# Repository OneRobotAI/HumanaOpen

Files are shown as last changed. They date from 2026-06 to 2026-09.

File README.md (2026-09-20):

# HumanaOpen

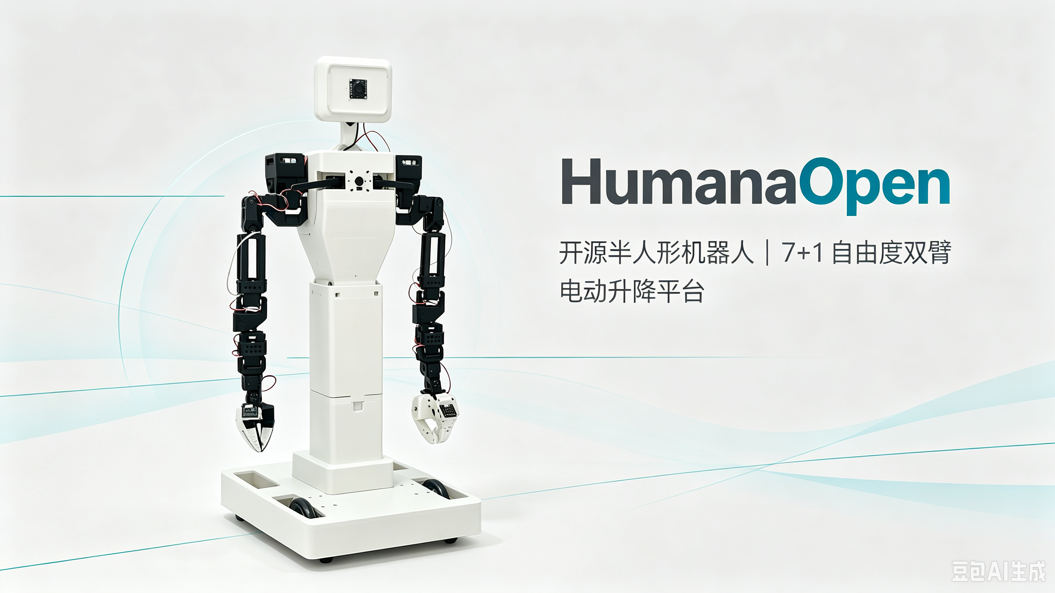
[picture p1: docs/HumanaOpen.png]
HumanaOpen


[English](README.md) | [中文](README_zh.md) | [Français](README_fr.md) | [한국어](README_ko.md)

**Open-source semi-humanoid robot — 7-DOF dual arms, differential drive, and leadscrew lift.**

Built on [LeRobot](https://github.com/huggingface/lerobot) and
[open-arms-mini](https://github.com/TheRobotStudio/open-arms-mini).

## Hardware

| Subsystem | Motors | Model |
|---|---|---|
| Left follower arm | 8 (7-DOF + gripper) | ST3215 C018 (1:345) |
| Right follower arm | 8 (7-DOF + gripper) | ST3215 C018 (1:345) |
| Head (pan/tilt) | 2 | ST3215 C018 (1:345) |
| Lift (leadscrew) | 1 | ST3250 (direct drive, no belt) |
| Differential drive base | 2 | ST3215 C018 (1:345) |
| Leader arms (teleop) | 2 × 8 | STS3215 C046 (1:147) |

> **Left/right convention**: Defined from the robot's own frame of reference.
> Standing behind the robot and facing the same direction as it, the arm on your
> left-hand side is the **left arm** (`port1`), the arm on your right-hand side is
> the **right arm** (`port2`). Wiring decides which physical arm is which; the
> software simply maps `left_arm_*` → `port1` and `right_arm_*` → `port2`.

## Software

```
lerobot_robot_humanaopen/
├── __init__.py              # Package exports
├── config_humanaopen.py     # HumanaOpenConfig, host/client configs
├── humanaopen.py            # HumanaOpen Robot class (follower)
├── lift_axis.py             # Lift axis with stall-detection homing
├── leader.py                # Leader teleoperator (single/bimanual)
├── humanaopen_host.py       # ZMQ host (robot-side, for dual-machine mode)
└── humanaopen_client.py     # ZMQ client (teleop-side)
examples/
├── record_data.py              # Data collection (single + dual-machine)
├── eval_data.py                # Inference (single + dual-machine)
├── teleop_leader_to_follower.py  # Full-body teleop: leader arms + keyboard
├── single_machine.py           # Single machine operation
├── teleop_keyboard.py          # Keyboard teleoperation via ZMQ
├── calibrate_follower.py       # Full follower-side calibration (arms+head+wheels+lift)
├── calibrate_leader.py         # Leader arm calibration (open-arms-mini)
├── diagnose_teleop.py          # Teleop joint direction diagnosis
├── test_base_keyboard.py       # Base-only keyboard test (no lift/arms)
├── test_lift_only.py           # Lift axis test (homing + raise/lower)
└── check_phase.py              # Check servo velocity unit (Phase BIT2)
```

## Hardware

```
hardware/
├── README.md               # Hardware overview (directory guide)
├── BOM/bom.md              # Bill of Materials — parts, specs, sourcing
├── assembly/assembly.md    # Step-by-step build instructions
├── cad/
│   ├── fusion360/          # Fusion 360 source designs (.f3d)
│   └── step/               # STEP exports (.step/.stp)
├── stl/                    # Ready-to-print 3D printing files (.stl)
├── urdf/                   # Robot description for RViz / Gazebo / simulation
│   └── humanaopen.urdf     # (meshes/ holds the referenced STL meshes)
└── electronics/wiring.md   # Wiring / electronics layout and power notes
```

### Diagnostics & Tuning Tools

| Script | Purpose |
|---|---|
| `diag_head_tilt_limits.py` | Head tilt mechanical range probe (before/after unlock) |
| `diag_head_tilt_range.py` | Head tilt range diagnostic |
| `diag_regression.py` | Regression test (lift + camera + teleop sequence) |
| `diag_st3250_speed.py` | ST3250 motor speed profiling (Phase BIT2=1) |
| `diag_follower_gripper.py` | Gripper joint diagnosis |
| `recover_lift_ping.py` | Lift motor communication ping |
| `speed_test_bit2_0.py` | BIT2=0 speed verification |
| `switch_phase_bit2.py` | Toggle ST3250 Phase BIT2 register |
```

## Quick Start

```bash
# 1. Create a conda env
conda create -n humanaopen python=3.12
conda activate humanaopen

# 2. Install LeRobot with all required extras (feetech + dataset + training + viz + hardware + smolvla)
pip install "lerobot[dataset,training,feetech,viz,transformers-dep,hardware,smolvla]"

# 3. Install HumanaOpen (editable)
cd /path/to/HumanaOpen
pip install -e . --no-deps

# Required: SOCKS proxy + SmolVLA tokenizer
pip install httpx[socks] num2words

# Optional: GPU with CUDA 12.8+ (Blackwell / RTX 5060+)
pip install torch torchvision torchaudio --index-url https://download.pytorch.org/whl/cu128

# 4. Verify installation
python -c "from lerobot_robot_humanaopen import HumanaOpen, HumanaOpenConfig; print('✅ OK')"

# 5. Verify installation (no calibration — just check import + connection)
python -c "
from lerobot_robot_humanaopen import HumanaOpen, HumanaOpenConfig
config = HumanaOpenConfig(port1='/dev/ttyACM0', port2='/dev/ttyACM1', port3=None, cameras={})
robot = HumanaOpen(config)
robot.connect(calibrate=False)
print(robot.get_observation().keys())
"

# 6. Dual-machine ZMQ mode (⚠️ for Jetson/Raspberry Pi deployment only — skip if single machine)
# See "Dual-Machine Deployment" section below for full setup guide.
```

## Dual-Machine Deployment

For production deployment, the robot hardware (servos + cameras) connects to an
embedded board (Jetson or Raspberry Pi), while the policy inference runs on a
separate GPU machine. The two communicate over ZMQ.

```
┌──────────────────────┐       ZMQ TCP        ┌──────────────────────┐
│   Dev Machine (GPU)  │ ←──────────────────→ │  Jetson / RPi (Host) │
│                      │   obs ──────────→    │                      │
│  • Policy inference  │   ←── action (21DOF) │  • Read servos/cams  │
│  • ACT / SmolVLA     │                       │  • Execute actions   │
│  • No servo wiring   │                       │  • Servo + cam wiring│
└──────────────────────┘                       └──────────────────────┘
```

### Raspberry Pi (Host only — no GPU inference)

```bash
# On Raspberry Pi (ARM64)
conda create -n humanaopen python=3.12
conda activate humanaopen

# Host dependencies (lightweight — no torch/transformers needed)
pip install pyzmq feetech-servo-sdk
# Optional: ffmpeg for video encoding (not needed if only streaming via ZMQ)
# conda install -y ffmpeg=7.1.1 -c conda-forge

# Install HumanaOpen
cd ~/ && git clone https://github.com/OneRobotAI/HumanaOpen.git
cd HumanaOpen && pip3 install -e . --no-deps

# Start Host — recommended: launcher script (bus topology + cameras via flags; same as teleop/record/eval scripts)
#   2-bus, no cameras                  python3 examples/humanaopen_host_launcher.py --no-cameras
#   2-bus, with cameras (default)      python3 examples/humanaopen_host_launcher.py
#   3-bus, with cameras                python3 examples/humanaopen_host_launcher.py --robot.port3 /dev/ttyACM2
#   3-bus, no cameras                  python3 examples/humanaopen_host_launcher.py --robot.port3 /dev/ttyACM2 --no-cameras
#   Override a camera device           python3 examples/humanaopen_host_launcher.py --head-camera /dev/video1
#   (--robot.port3 None = 2-bus; any device name = 3-bus. Defaults: head=/dev/video0, left_wrist=/dev/video2, right_wrist=/dev/video4)
#
# Equivalent inline form (also works):
python3 -c "
from lerobot_robot_humanaopen.humanaopen_host import HumanaOpenHost
from lerobot_robot_humanaopen import HumanaOpenConfig
from lerobot.cameras.opencv.configuration_opencv import OpenCVCameraConfig

HumanaOpenHost(HumanaOpenConfig(
    port1='/dev/ttyACM0', port2='/dev/ttyACM1', port3=None,
    cameras={
        'head':         OpenCVCameraConfig(index_or_path='/dev/video0', fps=30, width=640, height=480, fourcc='MJPG'),  # adjust /dev/videoN to match your board (lerobot-find-cameras)
        'left_wrist':   OpenCVCameraConfig(index_or_path='/dev/video2', fps=30, width=640, height=480, fourcc='MJPG'),  # adjust /dev/videoN to match your board (lerobot-find-cameras)
        'right_wrist':  OpenCVCameraConfig(index_or_path='/dev/video4', fps=30, width=640, height=480, fourcc='MJPG'),
                # 'chest': OpenCVCameraConfig(index_or_path='/dev/video6', fps=30, width=640, height=480, fourcc='MJPG'),  # 4th camera — uncomment to enable
    },
    wheel_dir_signs={'base_left_wheel': -1, 'base_right_wheel': 1}
)).run()
"
```

### NVIDIA Jetson (Host + optional local inference)

```bash
# On Jetson (JetPack 6.x, CUDA 12.x)
# Same installation as Raspberry Pi — Host does not need torch/transformers
conda create -n humanaopen python=3.12
conda activate humanaopen

pip install pyzmq feetech-servo-sdk
# conda install -y ffmpeg=7.1.1 -c conda-forge  # optional

cd ~/ && git clone https://github.com/OneRobotAI/HumanaOpen.git
cd HumanaOpen && pip3 install -e . --no-deps

# Start Host — recommended: launcher script (bus topology + cameras via flags; same as teleop/record/eval scripts)
#   2-bus, no cameras                  python3 examples/humanaopen_host_launcher.py --no-cameras
#   2-bus, with cameras (default)      python3 examples/humanaopen_host_launcher.py
#   3-bus, with cameras                python3 examples/humanaopen_host_launcher.py --robot.port3 /dev/ttyACM2
#   3-bus, no cameras                  python3 examples/humanaopen_host_launcher.py --robot.port3 /dev/ttyACM2 --no-cameras
#   Override a camera device           python3 examples/humanaopen_host_launcher.py --head-camera /dev/video1
#   (--robot.port3 None = 2-bus; any device name = 3-bus. Defaults: head=/dev/video0, left_wrist=/dev/video2, right_wrist=/dev/video4)
#
# Equivalent inline form (also works):
python3 -c "
from lerobot_robot_humanaopen.humanaopen_host import HumanaOpenHost
from lerobot_robot_humanaopen import HumanaOpenConfig
from lerobot.cameras.opencv.configuration_opencv import OpenCVCameraConfig

HumanaOpenHost(HumanaOpenConfig(
    port1='/dev/ttyACM0', port2='/dev/ttyACM1', port3=None,
    cameras={
        'head':         OpenCVCameraConfig(index_or_path='/dev/video0', fps=30, width=640, height=480, fourcc='MJPG'),  # adjust /dev/videoN to match your board (lerobot-find-cameras)
        'left_wrist':   OpenCVCameraConfig(index_or_path='/dev/video2', fps=30, width=640, height=480, fourcc='MJPG'),  # adjust /dev/videoN to match your board (lerobot-find-cameras)
        'right_wrist':  OpenCVCameraConfig(index_or_path='/dev/video4', fps=30, width=640, height=480, fourcc='MJPG'),
                # 'chest': OpenCVCameraConfig(index_or_path='/dev/video6', fps=30, width=640, height=480, fourcc='MJPG'),  # 4th camera — uncomment to enable
    },
    wheel_dir_signs={'base_left_wheel': -1, 'base_right_wheel': 1}
)).run()
"
```

> **Note**: Jetson can also run ACT inference locally (~100ms/frame on Orin),
> but SmolVLA requires a discrete GPU and should run on the dev machine.

### Dual-machine mode (--remote_ip)

All scripts (record, eval, teleop) support dual-machine mode via `--remote_ip`.
Single-machine mode (default) uses direct serial; dual-machine adds ZMQ:

```bash
# Single-machine (default — no --remote_ip needed)
python3 examples/record_data.py ...

# Dual-machine (add --remote_ip to any script)
python3 examples/record_data.py --remote_ip=192.168.1.100 --robot.cameras='{"head": {...}, "left_wrist": {...}, "right_wrist": {...}}'

python3 examples/eval_data.py --remote_ip=192.168.1.100 ...

python3 examples/teleop_leader_to_follower.py --remote_ip=192.168.1.100 ...
```

> **Note (recording)**: for `record_data.py` in dual mode, the `--remote_ip` script also
> passes the client-side camera list as a **schema** to define the dataset features.
> The Host must be started with the *same* cameras so it actually streams the images
> (start it with the camera configs, not `cameras={}`) — otherwise the recorded
> episodes contain state/action but no video.
>
> **Note (eval)**: the feature order of `observation.state` follows `robot.observation_features`
> (identical to training); `enable-base=true` keeps the `x.vel`/`theta.vel` columns.

### Network requirements

- Both machines on the same LAN (Ethernet recommended over WiFi for latency)
- Ports **5555** (commands) and **5556** (observations) must be open
- Image streaming bandwidth: ~10 Mbps per camera at 640x480 MJPG

### Performance

- **Control loop**: 60Hz (joint state read + action command)
- **Image capture**: 30fps (running in a dedicated background thread — does not block control)
- **Low latency**: image capture is decoupled from the control loop, so teleop arms respond
  instantly even at full 30fps image streaming
- **Configurable**: `image_fps_divider` (control/image rate ratio) and `max_loop_freq_hz` (control rate) in
  `HumanaOpenHostConfig`

### Wheel direction (dual-machine)

The robot's left wheel is mounted mirrored, so Host startup uses
`wheel_dir_signs={'base_left_wheel': -1, 'base_right_wheel': 1}`. This is set as the
default in `HumanaOpenConfig` — no need to pass it explicitly.

## Calibration

Calibration records the min/max range of each joint. **Only needed once** — the
results are saved and restored automatically on every connect.

### When to calibrate

- **First time setup** (required)
- After disassembling/reassembling arms or servos
- After replacing a servo motor
- After unlocking new motion range (e.g. head tilt EPROM unlock)

### Leader arm calibration

```bash
python3 examples/calibrate_leader.py
```

Steps (per arm):
1. Arm hanging straight down + gripper closed → `ENTER` (set zero point)
2. Move each joint through full range → `ENTER` (record real limits)
3. Gripper: close fully → `ENTER`, open fully → `ENTER`
4. Calibration saved automatically

> Requires leader arms powered at **7.4V** on `/dev/ttyACM2` (left) and `/dev/ttyACM3` (right).

Saved to:
```
~/.cache/huggingface/lerobot/calibration/teleoperators/humanaopen_leader/
├── leader_left.json
└── leader_right.json
```

### Follower calibration (arms + head + wheels + lift)

```bash
python3 examples/calibrate_follower.py
```

Steps:
1. Left arm + head: zero pose → `ENTER`; move joints through full range → `ENTER`
2. Right arm: zero pose → `ENTER`; move joints through full range → `ENTER`
3. Auto: wheels full range + lift stall homing to bottom

> Requires follower at **12V**. Torque is released during calibration — arms move freely.

Saved to:
```
~/.cache/huggingface/lerobot/calibration/robots/humanaopen/follower.json
```

## Teleoperation

### Full-body teleop (leader arms + keyboard)

`teleop_leader_to_follower.py` drives the follower's arms from the leader arms, and
head/base/lift from the keyboard:

| Control | Keys |
|---|---|
| Arms | leader arms follow (flips disabled — verified same-direction) |
| Head | `w`/`s` nod (up/down), `a`/`d` shake (left/right) |
| Base | `i`/`k` forward/back, `j`/`l` turn, `n`/`m` speed (0.3x/0.6x/1.0x) |
| Lift | `u`/`h` up/down (clamped 3–200mm) |
| Quit | `b` or Ctrl+C |

```bash
# Default: 3 cameras (head + left_wrist + right_wrist)
python3 examples/teleop_leader_to_follower.py

# Add the 4th chest camera
python3 examples/teleop_leader_to_follower.py --chest-camera /dev/video6

# Dual-machine: run Host on the robot, teleop on your PC
python3 examples/teleop_leader_to_follower.py --remote_ip=192.168.1.100 --chest-camera /dev/video6

# Teleop only, no cameras
python3 examples/teleop_leader_to_follower.py --no-cameras
```

##### Bus topology: 2-bus / 3-bus switch (`--robot.port3`)

The follower's serial buses are selected on the command line, so you can move
between layouts without editing code:

| Flag | Layout | Servos on each bus |
|---|---|---|
| *(omit)* / `--robot.port3 None` | **2-bus** (default) | bus1 = left arm + head, bus2 = right arm + **lift + wheels** |
| `--robot.port3 /dev/ttyACM2` | **3-bus** | bus1 = left arm + head, bus2 = right arm (exclusive), bus3 = lift + wheels |

The 3-bus layout takes the right arm off the bus shared with the lift/wheels,
giving it an uncontended bus (cleaner 60 Hz frame timing, less move-start
latency — most noticeable on the right arm). Both layouts run the same command;
`None` (or an empty value) selects 2-bus, a device name selects 3-bus:

```bash
# 2-bus (default): lift + wheels share port2 with the right arm
python3 examples/teleop_leader_to_follower.py

# Same thing, explicit
python3 examples/teleop_leader_to_follower.py --robot.port3 None

# 3-bus: give the lift + wheels their own serial port
python3 examples/teleop_leader_to_follower.py --robot.port3 /dev/ttyACM2

# Override other ports if your device names differ
python3 examples/teleop_leader_to_follower.py --robot.port1 /dev/ttyACM3 --robot.port2 /dev/ttyACM4
```

> The head servos (IDs 12, 13) stay on bus1 in both layouts — they are
> high-frequency (written every frame) like the left arm, while the lift/wheels
> are low-frequency (read every 10th frame), so bus3's job is to isolate the
> low-frequency group. Wiring note: the new port needs the same **GND
> common-ground** with the servo power supply.

#### Live display modes

`teleop_leader_to_follower.py` supports two visualization backends. Images are
decoded once by the control loop, then handed to a background display thread
so the 60 Hz control loop is never blocked.

| Flag | Backend | Notes |
|---|---|---|
| `--display=rerun` | [Rerun](https://rerun.io) native viewer | Native Rerun viewer window. |
| `--display=foxglove` | [Foxglove Studio](https://foxglove.dev) WebSocket | Connects Foxglove desktop or foxglove.dev to `ws://127.0.0.1:8765`. A layout is written to `examples/humanoopen_foxglove.layout.json` (import once). **Recommended** — lowest render latency of the two. |

Omit `--display` to run headless (no viewer).

```bash
# Foxglove (recommended)
python3 examples/teleop_leader_to_follower.py --remote_ip=192.168.1.100 --display=foxglove

# Rerun
python3 examples/teleop_leader_to_follower.py --remote_ip=192.168.1.100 --display=rerun
```

> **Display latency**: Both backends add a fixed render pipeline delay
> (≈1–1.5 s desktop / ≈2 s native viewer on this hardware) which is
> inherent to the visualization libraries. The action channel (arm
> commands) is real-time regardless; display lag does **not** affect
> recorded data quality — observation and action frames are always
> sampled synchronously.

Camera arguments: `--cameras=head,left_wrist` (subset), `--head-camera /dev/videoN`,
`--left-wrist-camera`, `--right-wrist-camera`, `--chest-camera` (each overrides the
device path; passing a `--*-camera` arg auto-adds that camera).

### Camera devices & fps (tested)

| Camera | Device | Format | FPS |
|---|---|---|-----|
| head | /dev/video0 | MJPG | 30 |
| left_wrist | /dev/video2 | MJPG | 30 |
| right_wrist | /dev/video4 | MJPG | 30 |
| chest | /dev/video6 | MJPG | 30 |

> **Adjusting FPS**: Check your camera's actual capabilities with
> `v4l2-ctl -d /dev/videoN --list-formats-ext`, then update the `fps` value in scripts.
> Setting an unsupported fps will cause a connection error at startup.

### Lift axis — zero persistence (免归零)

The lift is a 12-bit single-turn encoder (4096 ticks/rev) driving a leadscrew
(25 revs = 200mm). Absolute position is tracked in software via multi-turn wrap
tracking. Because the leadscrew is self-locking, the mechanical position survives
power cycles — so the zero position is persisted to `~/.cache/humanaopen/lift_zero.json`
and restored on the next connect, **skipping re-homing**:

- First connect: homes to the bottom (stall detection), saves the zero.
- Later connects: restores the saved absolute position (no movement needed).
- If the position changed (e.g. the lift was moved manually), restore fails and
  auto-homing runs instead.

Lift tuning (tested): `v_max=110` (raw), `kp_vel=10`, `home_down_speed=10` with
Phase BIT2=0 (50 step/s per raw unit). Max speed ≈ 8.7mm/s (200mm in ~23s).

### Lift speed boost (BIT2=0)

The ST3250 firmware maps `Goal_Velocity` with Phase BIT2=1 at 1 step/s per raw unit,
where raw > 1000 wraps direction (triangular wave) — unsafe. Switching Phase BIT2=0
changes the unit to 50 step/s per raw, so full speed (5500 step/s) is just raw 110,
entirely inside the reliable range. **After switching, all velocity params must be
divided by 50** (`home_down_speed`, `kp_vel`, `v_max`). Tools:
`examples/switch_phase_bit2.py` (toggle), `examples/speed_test_bit2_0.py` (verify).

> **Modern code does this automatically**: `lift_axis.configure()` reads the Phase
> register on every startup and, if BIT2=1 is detected, rewrites it to BIT2=0 (EPROM
> write — persists across reboots). `Acceleration` is also forced to 254 (fastest
> ramp) so commanded speeds are actually reached. No manual switching needed.

**After replacing the lift servo (safest manual fallback)**: a new servo ships with
Phase BIT2=1 (factory default), and the old `~/.cache/humanaopen/lift_zero.json`
holds the previous motor's encoder data — both need handling.

```bash
# 1. Remove the stale zero file (new motor has a different encoder origin)
rm ~/.cache/humanaopen/lift_zero.json

# 2. Check / switch the velocity unit (new servo ships BIT2=1 → set BIT2=0)
python3 examples/check_phase.py          # report current BIT2
python3 examples/switch_phase_bit2.py    # switch BIT2 → 0

# 3. First boot with forced homing to write the new motor's true zero
python3 -c "
from lerobot_robot_humanaopen.humanaopen_host import HumanaOpenHost
from lerobot_robot_humanaopen import HumanaOpenConfig
HumanaOpenHost(HumanaOpenConfig(
    port1='/dev/ttyACM0', port2='/dev/ttyACM1', port3=None,
    cameras={}, force_lift_home=True
)).run()
"
```

> Normal startup already performs steps 2–3 automatically; running them manually is
> a belt-and-braces check after a motor swap before going back to the full flow.

### Head tilt range unlock

The head tilt servo had its EPROM position limits baked to [1430, 2096] (~58°),
which the calibration file copied — limiting tilt to -54°/+4°. Writing
`Min=0 / Max=4095` unlocks the mechanical range [1367, 2242] (-61.6°/+17.1°):
`examples/unlock_head_tilt.py --probe`. After unlocking, the calibration file
(`~/.cache/huggingface/lerobot/calibration/robots/humanaopen/follower.json`) was
updated to the real range.

## Data Collection

The `lerobot-record` CLI hardcodes official robot types and rejects `humanaopen`
as an unrecognized choice. Use the Python API wrapper `examples/record_data.py`
instead — it exposes the **same parameter names** as `lerobot-record` and prints
the equivalent CLI command on startup for reference.

### 3 cameras (default)

```bash
python3 examples/record_data.py \
    --robot.type=humanaopen \
    --robot.id=follower \
    --robot.port1=/dev/ttyACM0 \
    --robot.port2=/dev/ttyACM1 \
    --robot.port3=None \
    --robot.cameras='{"head": {"type": "opencv", "index_or_path": "/dev/video0", "width": 640, "height": 480, "fps": 30, "fourcc": "MJPG"}, "left_wrist": {"type": "opencv", "index_or_path": "/dev/video2", "width": 640, "height": 480, "fps": 30, "fourcc": "MJPG"}, "right_wrist": {"type": "opencv", "index_or_path": "/dev/video4", "width": 640, "height": 480, "fps": 30, "fourcc": "MJPG"}}' \
    --robot.confirm_lift_after_home=true \
    --teleop.type=humanaopen_teleop \
    --teleop.left_arm_port=/dev/ttyACM2 \
    --teleop.right_arm_port=/dev/ttyACM3 \
    --teleop.flip_joints='{"left": [], "right": []}' \
    --teleop.joint_remap='{}' \
    --dataset.repo_id=your-name/humanaopen_demo \
    --dataset.single_task="describe your task" \
    --dataset.num_episodes=2 \
    --dataset.episode_time_s=15 \
    --dataset.reset_time_s=10 \
    --dataset.fps=30 \
    --dataset.push_to_hub=true
```

### 4 cameras (with chest for navigation)

Same as above, but replace the `--robot.cameras` JSON to include chest:

```bash
    --robot.cameras='{"head": {"type": "opencv", "index_or_path": "/dev/video0", "width": 640, "height": 480, "fps": 30, "fourcc": "MJPG"}, "left_wrist": {"type": "opencv", "index_or_path": "/dev/video2", "width": 640, "height": 480, "fps": 30, "fourcc": "MJPG"}, "right_wrist": {"type": "opencv", "index_or_path": "/dev/video4", "width": 640, "height": 480, "fps": 30, "fourcc": "MJPG"}, "chest": {"type": "opencv", "index_or_path": "/dev/video6", "width": 640, "height": 480, "fps": 30, "fourcc": "MJPG"}}' \
```

> **Note**: camera names must be consistent across record / train / rollout.

### Dual-machine (ZMQ): Host on the robot, record on your PC

When the follower runs on the robot (with its own cameras) and the leader arms
are plugged into your PC, record over ZMQ. **Start the Host first**, then run
`record_data.py` on the PC:

```bash
# 1) On the robot (Jetson or Raspberry Pi, see "Installing: Raspberry Pi / Jetson"
#    above) — start the Host, then leave it running
#    (HumanaOpenHost(...).run() with port1/port2 + the 3 cameras).

# 2) On your PC — record (follower via ZMQ, leader via local serial ttyACM0/1)
python3 examples/record_data.py \
    --remote_ip=192.168.1.9 \
    --robot.cameras='{"head": {"type": "opencv", "index_or_path": "/dev/video0", "width": 640, "height": 480, "fps": 30, "fourcc": "MJPG"}, "left_wrist": {"type": "opencv", "index_or_path": "/dev/video2", "width": 640, "height": 480, "fps": 30, "fourcc": "MJPG"}, "right_wrist": {"type": "opencv", "index_or_path": "/dev/video4", "width": 640, "height": 480, "fps": 30, "fourcc": "MJPG"}}' \
    --teleop.left_arm_port=/dev/ttyACM0 \
    --teleop.right_arm_port=/dev/ttyACM1 \
    --teleop.flip_joints='{"left": [], "right": []}' \
    --teleop.joint_remap='{}' \
    --dataset.repo_id=your-name/humanaopen_demo \
    --dataset.single_task="describe your task" \
    --dataset.num_episodes=2 \
    --dataset.episode_time_s=15 \
    --dataset.reset_time_s=10 \
    --dataset.fps=30 \
    --dataset.push_to_hub=true \
    --display=foxglove
```

- `--remote_ip` switches to dual-machine mode: the follower connects to the Host
  over ZMQ (follower `port1/port2`, `--robot.type/id/port3` are **not** needed),
  while the leader arms use the PC's local serial ports.
- `--robot.cameras` is passed as a *schema* (names + resolutions); the Host owns
  the physical cameras and streams the images over ZMQ.
- `--display=foxglove` (optional) streams cameras + state to the Foxglove app on
  the PC (connect Studio to `ws://127.0.0.1:8765`); `--display=rerun` uses the
  native Rerun viewer. Omit `--display` to record headless.

### Controls during recording

| Control | Keys |
|---|---|
| Arms | leader arms follow (16 DOF) |
| Head | `w`/`s` nod, `a`/`d` shake (2 DOF) |
| Base | `i`/`k` forward/back, `j`/`l` turn (2 DOF, speed `n`/`m`) |
| Lift | `u`/`h` up/down with safety limits (1 DOF, clamped 3–200mm) |
| Record | `C` start, `Q` quit, `A` re-record episode |
| Confirm | After homing, hold `u`/`h` to position, `ENTER` to confirm |

The `--teleop.type=humanaopen_teleop` teleoperator records **all 21 DOF** — the
leader arms (16 joints) plus keyboard-controlled head/lift/base (5 DOF). Both are
saved into the dataset for ACT training.

### Lift behavior during recording

- On first connect: lift **homes to bottom** (stall detection), saves the zero
  position to `~/.cache/humanaopen/lift_zero.json`.
- On subsequent connects: lift **restores the saved position** (no homing needed),
  unless the position changed (manual push → restore fails → auto-home).
- After homing: keyboard hold `u`/`h` adjusts height with safety limits
  (3mm–200mm), `ENTER` to confirm and start recording.

### Resuming / cleaning datasets

If a dataset directory already exists from a previous run, delete it or resume:

```bash
rm -rf ~/.cache/huggingface/lerobot/your-name/humanaopen_demo    # fresh start
# or add --dataset.resume=true to the record_data.py command     # continue from last episode
```

### Live display while recording (optional)

By default recording runs headless (no viewer). To watch cameras + state in real
time while you teleoperate, add a display flag:

```bash
# Rerun viewer
python3 examples/record_data.py ... --display=rerun

# Foxglove app (recommended — lower render latency, same backend as teleop)
python3 examples/record_data.py ... --display=foxglove
# connect Foxglove Studio to ws://127.0.0.1:8765
```

> Display is decoupled from the control/recording loop, so it never perturbs the
> recorded `(observation, action)` frames. Like teleop, the viewer adds a fixed
> ~1–1.5 s render delay that does **not** affect data quality.

## Training

### ACT (action chunking transformer)

```bash
# Quick test (2 episodes)
lerobot-train \
    --policy.type=act \
    --policy.device=cuda \
    --policy.push_to_hub=true \
    --policy.repo_id=your-name/humanaopen_act_policy \
    --dataset.repo_id=your-name/humanaopen_act_demo \
    --output_dir=outputs/humanaopen_act_demo \
    --batch_size=3 \
    --steps=5

# Production (>50 episodes)
lerobot-train \
    --policy.type=act \
    --policy.device=cuda \
    --policy.push_to_hub=true \
    --policy.repo_id=your-name/humanaopen_act_policy \
    --dataset.repo_id=your-name/humanaopen_act_demo \
    --output_dir=outputs/humanaopen_act_demo \
    --batch_size=32 \
    --steps=50000
```

### SmolVLA (vision-language-action model)

SmolVLA requires the language instruction from `--dataset.single_task` (used during recording).
The VLM weights (~500M) are downloaded automatically from HuggingFace on first run.

```bash
# Quick test (2 episodes)
lerobot-train \
    --policy.type=smolvla \
    --policy.device=cuda \
    --policy.push_to_hub=true \
    --policy.repo_id=your-name/humanaopen_smolvla_policy \
    --dataset.repo_id=your-name/humanaopen_act_demo \
    --output_dir=outputs/humanaopen_smolvla_demo \
    --batch_size=4 \
    --steps=20
```

> **Note**: SmolVLA (~450M params) is ~20x heavier than ACT (~52M), uses more VRAM,
> and trains slower. Batch size 4 fits in 8GB VRAM (RTX 5060 Ti). For >50 episodes,
> increase steps to 20000+.

### Key parameters

| Parameter | Default | Description |
|---|---|---|
| `--policy.type` | — | **Required.** `act`, `smolvla`, `diffusion`, etc. |
| `--policy.device` | `cuda` | `cuda` / `cpu`. |
| `--policy.push_to_hub` | `true` | Push model to HuggingFace Hub. |
| `--policy.repo_id` | — | Hub repo for the trained model. Required when pushing. |
| `--dataset.repo_id` | — | **Required.** Hub repo of the training dataset. |
| `--output_dir` | — | Local checkpoint directory. |
| `--batch_size` | 8 | Samples per step. ACT: 32, SmolVLA: 4 (8GB VRAM limit). |
| `--steps` | 100000 | Total training steps. ACT: 50K, SmolVLA: 20K. |

### Outputs

```
outputs/humanaopen_act_demo/
├── pretrained_model/           # Full model (config + weights)
├── last/pretrained_model       # Latest checkpoint
├── train_logs/                 # Training metrics (TensorBoard-compatible)
└── training_state.json         # Optimizer/scheduler state for resume
```

The pushed model will be at `https://huggingface.co/your-name/humanaopen_act_policy`.

## Inference (Deployment)

> **Dependencies**: SmolVLA requires `transformers>=4.48` and `num2words`.
> Install with `pip install transformers>=4.48 num2words` before running SmolVLA inference.

### ACT inference

**Dual-machine (recommended):** the robot runs a Host (Jetson/Raspberry Pi) with the
cameras; `eval_data.py` connects to it over ZMQ on your PC. Start the Host first, then:

```bash
# On the robot (Jetson or Raspberry Pi) — start the Host and leave it running
#   (HumanaOpenHost(...).run() with port1/port2 + the 3 cameras).

# On your PC — run inference
python3 examples/eval_data.py \
    --policy.type=act \
    --policy.repo_id=your-name/humanaopen_act_policy \
    --policy.device=cuda \
    --remote_ip=192.168.1.9 \
    --robot.cameras='{"head": {"type": "opencv", "index_or_path": "/dev/video0", "width": 640, "height": 480, "fps": 30, "fourcc": "MJPG"}, "left_wrist": {"type": "opencv", "index_or_path": "/dev/video2", "width": 640, "height": 480, "fps": 30, "fourcc": "MJPG"}, "right_wrist": {"type": "opencv", "index_or_path": "/dev/video4", "width": 640, "height": 480, "fps": 30, "fourcc": "MJPG"}}' \
    --enable-base=false \
    --enable-lift=false \
    --num-episodes=5 \
    --duration=30 \
    --fps=30 \
    --display=foxglove
```

- `--remote_ip` switches to dual-machine mode: the follower connects to the Host
  over ZMQ (no `--robot.port1/port2/port3`); the cameras live on the Host.
- `--display=foxglove` (optional) streams to the Foxglove app on the PC
  (connect Studio to `ws://127.0.0.1:8765`). Omit `--display` for headless inference.

**Single-machine** (follower directly on serial ports, same machine):
```bash
python3 examples/eval_data.py \
    --policy.type=act \
    --policy.repo_id=your-name/humanaopen_act_policy \
    --policy.device=cuda \
    --robot.type=humanaopen \
    --robot.id=follower \
    --robot.port1=/dev/ttyACM0 \
    --robot.port2=/dev/ttyACM1 \
    --robot.port3=None \
    --robot.cameras='{"head": {"type": "opencv", "index_or_path": "/dev/video0", "width": 640, "height": 480, "fps": 30, "fourcc": "MJPG"}, "left_wrist": {"type": "opencv", "index_or_path": "/dev/video2", "width": 640, "height": 480, "fps": 30, "fourcc": "MJPG"}, "right_wrist": {"type": "opencv", "index_or_path": "/dev/video4", "width": 640, "height": 480, "fps": 30, "fourcc": "MJPG"}}' \
    --enable-base=false \
    --enable-lift=false \
    --num-episodes=5 \
    --duration=30 \
    --fps=30
```

### SmolVLA inference (language-conditioned)

**Dual-machine (recommended):** same as ACT — start the Host on the robot, run on
your PC over ZMQ:

```bash
# On the robot — start the Host and leave it running.

# On your PC
python3 examples/eval_data.py \
    --policy.type=smolvla \
    --policy.repo_id=your-name/humanaopen_smolvla_policy \
    --policy.device=cuda \
    --task="wave hello with both arms" \
    --remote_ip=192.168.1.9 \
    --robot.cameras='{"head": {"type": "opencv", "index_or_path": "/dev/video0", "width": 640, "height": 480, "fps": 30, "fourcc": "MJPG"}, "left_wrist": {"type": "opencv", "index_or_path": "/dev/video2", "width": 640, "height": 480, "fps": 30, "fourcc": "MJPG"}, "right_wrist": {"type": "opencv", "index_or_path": "/dev/video4", "width": 640, "height": 480, "fps": 30, "fourcc": "MJPG"}}' \
    --enable-base=false \
    --enable-lift=false \
    --num-episodes=2 \
    --duration=10 \
    --fps=10 \
    --display=foxglove
```

**Single-machine** (follower directly on serial):
```bash
python3 examples/eval_data.py \
    --policy.type=smolvla \
    --policy.repo_id=your-name/humanaopen_smolvla_policy \
    --policy.device=cuda \
    --task="wave hello with both arms" \
    --robot.type=humanaopen \
    --robot.id=follower \
    --robot.port1=/dev/ttyACM0 \
    --robot.port2=/dev/ttyACM1 \
    --robot.port3=None \
    --robot.cameras='{"head": {"type": "opencv", "index_or_path": "/dev/video0", "width": 640, "height": 480, "fps": 30, "fourcc": "MJPG"}, "left_wrist": {"type": "opencv", "index_or_path": "/dev/video2", "width": 640, "height": 480, "fps": 30, "fourcc": "MJPG"}, "right_wrist": {"type": "opencv", "index_or_path": "/dev/video4", "width": 640, "height": 480, "fps": 30, "fourcc": "MJPG"}}' \
    --enable-base=false \
    --enable-lift=false \
    --num-episodes=2 \
    --duration=10 \
    --fps=10
```

> **SmolVLA performance note**: VLM inference is ~1s/frame (450M params). A 10s
> episode at 10fps = 100 frames ≈ 100s wall clock time. For real-time deployment,
> use ACT (~50ms/frame). SmolVLA is best for language-conditioned tasks.

### Live display during inference (optional)

Display is off by default. Add `--display` to stream the rollout live:

```bash
# Foxglove app (recommended — lower render latency)
python3 examples/eval_data.py ... --display=foxglove
# connect Foxglove Studio to ws://127.0.0.1:8765

# Rerun native viewer
python3 examples/eval_data.py ... --display=rerun

# Headless (default): omit --display
python3 examples/eval_data.py ...
```

> Display runs in a background thread so it never slows the policy loop. Like
> teleop/record, the ~1–1.5 s render delay is inherent to the viewer and does not
> affect control.

### Base control (disable by default)

By default the base wheels are **disabled** (`--enable-base=false`): the policy's
predicted `x.vel` / `theta.vel` are forced to `0`, so only the arms, head and lift
move. This prevents the robot from driving away unexpectedly, which is safer while
validating a new policy.

```bash
# Base disabled (default, safer) — wheels stay still, only arms/head/lift move
python3 examples/eval_data.py ... --enable-base=false

# Base enabled — policy is allowed to drive the wheels
python3 examples/eval_data.py ... --enable-base=true
```

Start with `--enable-base=false` until the policy behaves well, then enable the
base if your task requires locomotion.

### Lift control (hold height by default)

By default the lift is **held at its current height** (`--enable-lift=false`): the
policy's `lift_axis.height_mm` is overridden to the current height each frame, so
the lift does not move (the policy can otherwise output 0 and drag the lift to the
bottom).

```bash
# Lift held at current height (default, safer) — the lift stays put
python3 examples/eval_data.py ... --enable-lift=false

# Lift enabled — policy controls the lift height
python3 examples/eval_data.py ... --enable-lift=true
```

Start with the lift held, then enable it once your task requires changing height.

### Controls during inference

| Control | Keys |
|---|---|
| Quit | `q` or Ctrl+C |

### Safety: torque release on exit

When you press `q` / Ctrl+C to stop inference, the script will:
1. **Stop the base wheels** (send `x.vel=0 / theta.vel=0` as the final command) and
   hold the lift at its current height
2. Save the lift position
3. Prompt: **"Press ENTER to release torque and disconnect..."**
4. Hold the arms before pressing ENTER — torque will be released and arms drop freely
5. Press ENTER when ready → disconnect

This prevents arms from suddenly dropping when servos lose power.

**Base/lift auto-stop safety net (dual-machine):** the Host runs a watchdog — if it
receives no action command for `watchdog_timeout_ms` (500 ms), it zeroes the wheel
velocity and holds the lift. So even if the PC process is killed abruptly
(`kill -9`) or disconnects while the wheels are moving, the base stops on its own
instead of continuing to drive until the Host is stopped.

### Key parameters (inference)

| Parameter | Default | Description |
|---|---|---|
| `--policy.type` | `act` | `act` or `smolvla`. |
| `--policy.repo_id` | — | **Required.** Hub repo of the trained model. |
| `--task` | — | Language instruction (required for SmolVLA). |
| `--enable-base` | `false` | Set `true` to allow policy control of base wheels. Default: disabled. |
| `--enable-lift` | `false` | Set `true` to let the policy control the lift height. Default: held at current height. |
| `--num-episodes` | 5 | Number of inference episodes. |
| `--duration` | 30 | Seconds per episode. |
| `--fps` | 30 | Inference frequency (Hz). |

On startup, the script will prompt for calibration confirmation (ENTER to restore).
On exit, it will prompt for torque release confirmation (ENTER to release).

## Navigation

Language-driven navigation powered by [LightNav-0](https://github.com/kyonofx/LightNav-0) — a vision-language-action model running on your GPU PC. The robot only runs a light ZMQ adapter; no LightNav install, no ROS, no lidar, no map needed. Just a forward RGB camera plus the GPU server over the network.

```
[chest camera /dev/video0] ──cv2──> [adapter on Jetson] ──WS──> lightnav-serve (GPU PC, :8050)
        ^                                   |
        |                                   | 10×SE(2) waypoints / step
  HumanaOpenHost <──ZMQ :5555── [control law: official waypoint_command]
```

Quick start (on the robot, two terminals):

```bash
# Terminal 1 — Host in pure-base mode (no camera streaming; adapter reads the chest cam itself)
python3 -c "
from lerobot_robot_humanaopen.humanaopen_host import HumanaOpenHost
from lerobot_robot_humanaopen import HumanaOpenConfig

HumanaOpenHost(HumanaOpenConfig(
    port1='/dev/ttyACM0', port2='/dev/ttyACM1', port3=None,
    cameras={},
    wheel_dir_signs={'base_left_wheel': -1, 'base_right_wheel': 1}
)).run()
"

# Terminal 2 — navigation adapter (GPU PC must have lightnav-serve listening on 0.0.0.0:8050)
NO_PROXY="192.168.1.12" python3 examples/lightnav_navigation.py \
    --lightnav ws://192.168.1.12:8050 \
    --camera /dev/video0 \
    --instruction "walk forward slowly"
```

Key points:
- **English instructions only** (model is English-trained); e.g. `"walk forward slowly"`, `"go to the object on your left"`.
- `NO_PROXY=<gpu_ip>` is required on the robot: the `websockets` client reads proxy env vars and will fail to reach the LAN GPU server otherwise.
- RVQ quantization traps (waypoint yaw = ±0.314 rad for "no turn", 0.15 m steps) are handled inside the adapter via the official `waypoint_command` control law + deadbands — see `docs/navigation/lightnav_integration.md` §八/§九 for the full pitfall log.

## Roadmap

| Module | Status |
|---|---|
| ACT, SmolVLA | ✅ |
| BOM | ✅ |
| Assembly | ✅ |
| CAD | ✅ |
| Lite version | ☐ |
| URDF | ☐ |
| Agent | ☐ |
| Vision-based grasping | ☐ |
| Vision-based navigation | ✅ |
| Embodied world models | ☐ |

### Acknowledgements

- Software is built on [LeRobot](https://github.com/huggingface/lerobot) and
  [open-arms-mini](https://github.com/TheRobotStudio/open-arms-mini).
- The arms are based on open-arms-mini, with a [PincOpen](https://github.com/pollen-robotics/PincOpen?tab=readme-ov-file) gripper added at the end of each arm.
- Hardware design references [xlerobot](https://github.com/xrobot/xlerobot):
  the head degrees-of-freedom and the differential-drive base follow its
  approach.

## Contact & Cooperation

- **Product Communication**: scan the QR code to reach our product team:

Product communication QR code

## License

Apache 2.0

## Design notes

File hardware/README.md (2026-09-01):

# Hardware

The mechanical / electrical / printable design files for HumanaOpen.

## Directory layout

| Path | Contents |
|---|---|
| [`BOM/`](BOM/bom.md) | Bill of Materials — every part needed to build the robot, with specs, quantity, and sourcing. |
| [`assembly/`](assembly/assembly.md) | Step-by-step build instructions (subsystems: arms, head, lift, base, electronics). |
| [`cad/`](cad/) | CAD source files. |
| `cad/fusion360/` | Fusion 360 source design files (`.f3d`). |
| `cad/step/` | STEP file exports (`.step`/`.stp`, open, importable anywhere). |
| [`stl/`](stl/) | Ready-to-print 3D printing files (`.stl`). |
| [`urdf/`](urdf/) | Robot description (`.urdf` / `.xacro`) for RViz / Gazebo / simulation. |
| `urdf/meshes/` | Mesh files referenced by the URDF (may reuse the STL meshes). |
| [`electronics/`](electronics/wiring.md) | Wiring / electronics layout and power notes. |

## Conventions

- **Units**: STL/STEP are in millimetres (mm).
- **URDF**: inertial properties should be filled from the CAD export so
  simulation matches the physical robot.
- Keep every exported STEP/STL in sync with the Fusion 360 source: re-export
  after any design change and note the revision in the file name or this README.

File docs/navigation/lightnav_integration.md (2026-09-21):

# HumanaOpen 导航 — LightNav-0 集成调研与实施方案

> 状态：**调研完成，模拟验证通过，实机接入完成（直行 + 转向测试通过）**
> 日期：2026-09-17（调研）/ 2026-09-18（实机接入）
> 硬件：PC (RTX 5060 Ti 16GB) 为 GPU 推理服务器，Jetson 为机器人端

## 一、结论摘要

- **LightNav-0 可行**：已在 PC 上完成环境安装、模型加载、MuJoCo 模拟语言导航全链路验证（全 PASS）。
- **HumanaOpen 代码零修改**：导航作为"外挂"，通过约 50 行 ZMQ adapter 与 HumanaOpen 底盘接口衔接。
- **不需要 ROS 层**（最小方案）；ROS 2 完整栈是可选升级，非前提。
- **传感器需求极简**：只需一个前向 RGB 摄像头（无激光雷达、无深度、无地图、无里程计）。

## 二、LightNav-0 是什么

- **VLM 导航模型**（Qwen3-VL-4B 底座）：输入单目 RGB 历史帧 + 自然语言指令 → 输出 10 个 SE(2) 未来航点 `[forward_m, lateral_m, yaw_rad]`。
- **不是 SLAM / move_base / 地图框架**：无定位、无建图、无障碍感知层；纯端到端视觉语言 → 航点，每帧重规划。
- 单模型覆盖：语言指令导航（VLN）、开放词汇找物（ObjectNav）、视觉目标追踪（EVT），跨机器人零样本迁移（官方演示过 humanoid/quadruped/wheeled/aerial）。
- 项目主页/源码：`lightorigins/LightNav-0`，Apache 2.0，arXiv 2608.30935。
- 模型权重：HuggingFace `LightOriginsHQ/LightNav-0`（需 HF 登录；仓库内文件 ~9.6GB）。

## 三、硬件与运行要求

| 项 | 要求 | 实测（本机 5060 Ti） |
|---|---|---|
| GPU | ~15GB 显存（4B bf16 ~10GB + KV cache ~2.3GB）| ✅ 16GB 可用，占用 ~8.7GiB |
| 架构 | 官方验证 sm_103 (B300)；消费级 Blackwell (sm_120) 实测可跑 | ✅ |
| Python | >=3.11, <3.12 | ✅ 独立 conda 环境 `lightnav` |
| torch | >=2.9；**Blackwell 需 cu129 wheel**（2.10.0+cu129）| ✅ |
| vLLM | **0.19.1 精确锁定**（绑定私有 API）| ✅ |
| 推理延迟 | 官方 60-150ms/步；本机实测 644ms/步（warmup 后）| 可用 |

传感器：**单目 RGB 前向摄像头**（参考：Orbbec Gemini 330, 640×360@30；任意 rgb8 相机可）。
机器人：任意移动底盘；官方参考 Unitree Go2 / LimX TRON1；**MuJoCo demo 用差速 TurtleBot（与 HumanaOpen 同运动学）**。

## 四、部署架构（与 HumanaOpen 的关系）

```
┌─ LightNav 世界 ─────────────┐      ┌─ HumanaOpen 世界 ─────────────┐
│ GPU 服务器 (PC)              │      │ Jetson 机器人端                 │
│  lightnav-serve :8050        │      │  HumanaOpenHost (ZMQ 5555/5556) │
│  ←WebSocket JSON→            │      │  底盘吃 x.vel / theta.vel       │
│        │                     │      │                                │
│        └─ 航点 → ZMQ adapter ─┼────▶│  差速电机                      │
│    (adapter 约 50 行 Python) │      │                                │
└──────────────────────────────┘      └────────────────────────────────┘
```

- **模型服务器**：GPU 机器（PC），跑 `lightnav-serve`，是独立 conda 环境 `lightnav`。
- **客户端（adapter）**：Jetson 上，相机 → JPEG → WebSocket `next` → 拿航点 → 换算 `v=forward/dt, w=yaw/dt` → ZMQ 发给 HumanaOpenHost 的 `x.vel/theta.vel`。
- **HumanaOpen 代码不改**：adapter 只向已有的 ZMQ action 塞值。

### 可选：ROS 2 完整栈（暂不采用）
官方 `robot_deploy/` 是 ROS 2 Humble 栈（相机驱动 + vln_client + vln_mpc + vln_web + 适配器），提供 MPC 平滑、Web 控制面板、看门狗、手自动切换。**需要装 ROS 2 + 写 humano_adapter**，工作量大，暂缓。

## 五、安装步骤（已在 PC 完成，存档）

```bash
# 1. 独立 Python 3.11 环境
conda create -n lightnav python=3.11 -y
conda activate lightnav

# 2. Blackwell 必需：cu129 torch（普通 cu12.8 无法 JIT）
pip install torch==2.10.0+cu129 torchvision==0.25.0+cu129 \
  --index-url https://download.pytorch.org/whl/cu129

# 3. LightNav 本体
cd ~/LightNav-0
pip install -e ".[vllm,video]"

# 4. HF 登录（代理环境需先装 socksio）
pip install "httpx[socks]"
hf auth login --token <TOKEN> --add-to-git-credential

# 5. 下载权重
mkdir -p checkpoints/LightNav-0
hf download LightOriginsHQ/LightNav-0 --local-dir checkpoints/LightNav-0

# 6. GPU 冒烟测试（全 PASS 才继续）
MODEL_PATH=checkpoints/LightNav-0 bash scripts/smoke_gpu.sh
```

## 六、启动模型服务器（GPU 机器上常驻）

```bash
cd ~/LightNav-0 && conda activate lightnav
CUDA_VISIBLE_DEVICES=0 GPU_MEM_UTIL=0.78 \
HOST=0.0.0.0 PORT=8050 lightnav-serve \
    --task vln \
    --model_path checkpoints/LightNav-0 \
    --backend vllm_local
```

- 监听 `127.0.0.1:8050`（本机）。**要让 Jetson 连接必须监听对对外地址**，启动前确认 `lightnav-serve` 的 host 参数（或设 `--host 0.0.0.0`）。
- 首次启动含模型加载+JIT 编译约 1-2 分钟；之后单步推理约 100-644ms。
- 显存不够时把 `GPU_MEM_UTIL` 降到 0.70。

## 七、MuJoCo 模拟验证（已通过）

```bash
# 服务终端保持运行，另开终端：
cd ~/LightNav-0/mujoco_demo
./run.sh --vln-server ws://127.0.0.1:8050
# 浏览器打开 http://127.0.0.1:8088，输入英文指令（如 "walk to the red trash can"）
```

- 模拟差速 TurtleBot（与 HumanaOpen 同运动学）在 ProcTHOR 室内场景语言导航。
- 模型英文训练，**中文指令不支持**，请用英文。

## 八、接入 HumanaOpen（已实施）

### ZMQ adapter（实际实现：`examples/lightnav_navigation.py`）

在 Jetson 上运行（Jetson 只需 `pip install websockets`，无需安装 LightNav/GPU 推理——模型全部在 PC 上跑）：

```bash
cd ~/HumanaOpen && git pull
# 启动 HumanaOpenHost（纯底盘，相机由 adapter 自抓）
python3 -c "
from lerobot_robot_humanaopen.humanaopen_host import HumanaOpenHost
from lerobot_robot_humanaopen import HumanaOpenConfig

HumanaOpenHost(HumanaOpenConfig(
    port1='/dev/ttyACM0', port2='/dev/ttyACM1', port3=None,
    cameras={},   # 导航不需要 host 传图，adapter 自己抓 chest 相机
    wheel_dir_signs={'base_left_wheel': -1, 'base_right_wheel': 1}
)).run()
"
# 另一个终端：跑导航 adapter
NO_PROXY="192.168.1.12" python3 examples/lightnav_navigation.py \
    --lightnav ws://192.168.1.12:8050 \
    --zmq-host 127.0.0.1 \
    --camera /dev/video0 \
    --instruction "walk forward slowly"
```

工作流程：
1. `cv2` 抓 chest 相机一帧 → JPEG（q80，640x360）→ WebSocket 发给 PC 的 lightnav-serve
2. 服务返回 10 个 SE(2) 航点 `[forward_m, lateral_m, yaw_rad]`（RVQ 量化）
3. **控制律**（移植 LightNav 官方 mujoco demo 的 `waypoint_command`，非"航点÷dt"的朴素除法）：
   - 只用 `waypoints[0]`（当前帧的动作；后面的是预测路径，用了会放大 atan2 噪声导致满档旋转）
   - distance < 0.08m → 视为量化噪声，静止 `(0,0)`
   - `angular = clamp(1.8·bearing + 0.25·target_yaw)`，bearing/yaw 各带死区滤量化电平
   - `linear = clamp(0.75·distance·cos(bearing), 0, 0.35)`；`|bearing|>65°` 时 linear=0（先转向再前进）
4. `{"x.vel": v m/s, "theta.vel": w deg/s}` 经 ZMQ PUSH 发到 HumanaOpenHost:5555

关键点：
- `stop=true` 或航点空 → 发 `{x.vel:0, theta.vel:0}`；Ctrl+C 也会主动归零（而非只靠 watchdog）
- **RVQ 量化陷阱**（实机踩坑记录）：action tokenizer 把"无转向"量化成 `yaw=±0.314`（≈±π/10），把"直行一步"量化成 `forward≈0.15m`。直接 `yaw/dt` 会得到 ±72°/s 的疯狂自转；直接 `forward/dt` 是 0.6 m/s 的冲撞速度。必须用上述官方控制律 + 死区。
- **代理变量**：`websockets` 库会读 http/socks 代理环境变量，Jetson 上连局域网 GPU 必须 `NO_PROXY=192.168.1.12`，否则连不上。
- **语音/中文**需要额外 ASR/翻译层（模型英文训练）——不在当前方案范围。

### 相机
- 实机使用 Jetson 的 `Integrated_Webcam_HD`（USB，原生 MJPG 1280x720@30 / YUYV 640x480@25）作为 **chest 前向相机 `/dev/video0`**。
- 注意：这台相机 lerobot 的 `OpenCVCamera` 无法设置分辨率（`set()` 恒返回 False），因此 host 用 `cameras={}` 纯底盘模式，图像完全由 adapter 的 `cv2` 直接抓取（`cv2.VideoCapture` 读 `/dev/video0` 正常）。
- 模型内部把任意分辨率缩放到其 `video_size`，客户端只需 JPEG 编码。

## 九、实机验证结果（2026-09-18）

### 环境
- Jetson（host，`humanaopen` conda env，Python 3.12）：HumanaOpenHost 纯底盘模式 + adapter；唯一外设：chest 相机 `/dev/video0`
- PC（GPU，`lightnav` env）：lightnav-serve 常驻 `0.0.0.0:8050`，模型 8.7GiB 显存

### 关键数据
| 项 | 实测 |
|---|---|
| 单帧推理延迟（Jetson→PC→Jetson RTT） | **~200-350ms**（比 644ms 的纯本机 warmup 快，服务常驻后更稳）|
| 直行 `"walk forward slowly"` | **0.113 m/s 平稳直行**，无自转、无抖动 |
| 左转弧线 `"go to the object on your left"` | **0.11 m/s + 15°/s 左转**（模型输出 lateral=0.022m → bearing=8.4° → 1.8×=15°/s）|
| 静止（噪声航点）| **精确归零**——RVQ 量化噪声（yaw=±0.314）被死区滤掉，不再 ±72°/s 狂转 |
| Watchdog 联动 | host 500ms 超时正常；adapter 4Hz 控制周期在超时内 |

### 踩坑记录（按时间顺序）
1. **`host+cameras` 启动崩溃**：`OpenCVCamera(/dev/video0)` 校验失败——这台 USB 相机 `set(CAP_PROP_*)` 恒返 False，`lerobot` 把它当失败。→ 改用 `cameras={}` 纯底盘模式。
2. **±72°/s 自转**（首批测试）：直接 `yaw/dt`，量化 `±0.314rad` 变成满档旋转。→ 引入官方 `waypoint_command`。
3. **±45°/s 抖动**（第二批）：官方 0.35m 距离门槛在 0.15m 步长下全被当噪声，回退 `valid[-1]` 放大 atan2 符号噪声。→ 门槛降到 0.08m + bearing/yaw 死区。
4. **-45°/s 残留**（第三批）：搜索"第一个够远点"时，序列后面的远点 bearing 极大，overrode waypoint[0]。→ 只用 `waypoint[0]` 作为当前帧动作。

### 结论
- **导航链路完整可用**：相机 → GPU 推理 → 控制律 → 底盘，全部打通。
- 模型对"左右/前进"的语义理解正确，会输出对应的横向位移 + 转向组合。
- 当前速度保守（0.11 m/s、15°/s）；调参可改 `--max-linear` / `--max-angular`。

## 十、风险与注意

| 项 | 说明 |
|---|---|
| **无避障** | 模型只看 RGB，感知不到视野外的障碍；紧急停止靠 `stop` 标志 + 用户 WASD/手动控制 |
| **延迟** | 实测单步 ~200-350ms（约 3-5Hz 重规划）；远距离移动建议用平滑器，不能每步都突变 |
| **中文指令** | 模型英文训练；中文需要先做翻译/ASR |
| **服务对外** | lightnav-serve 必须监听 `0.0.0.0` 才能被 Jetson 连（`HOST=0.0.0.0` 环境变量） |
| **代理** | Jetson 连 `ws://192.168.1.12:8050` 需 `NO_PROXY=192.168.1.12`（websockets 读代理变量） |
| **显存** | 16GB 偏紧；跑服务时关闭其他 GPU 大程序 |
| **换伺服/换环境** | 不影响导航（导航只依赖相机+GPU） |

## 文件结构

```
docs/navigation/
└── lightnav_integration.md    # 本文档（HumanaOpen 侧）
HumanaOpen 侧实现:
examples/lightnav_navigation.py  # ZMQ adapter：相机抓帧 → ws → 控制律 → 底盘
External:
~/LightNav-0/                   # LightNav 仓库（独立项目，不并入 HumanaOpen）
  ├── src/lightnav/             # 模型推理 + WebSocket 服务
  ├── robot_deploy/             # （可选）ROS2 参考栈
  ├── mujoco_demo/              # 差速机器人仿真（已验证）
  └── docs/                     # PROTOCOL/DEPLOYMENT/CONFIGURATION
```

## 十一、后续路线

- [x] 环境安装 + GPU 冒烟测试（全 PASS）
- [x] 模型服务启动
- [x] MuJoCo 模拟语言导航验证
- [x] 确认 Jetson 前向相机（chest `/dev/video0`，`Integrated_Webcam_HD`）
- [x] 让服务监听 0.0.0.0
- [x] 编写 ZMQ adapter（Jetson 上，`examples/lightnav_navigation.py`）
- [x] HumanaOpen + LightNav 实机端到端测试（直行 + 左转弧线均通过）
- [ ] 避障增强（当前模型无避障，仅 RGB 语义导航）
- [ ] 调参优化速度/转向手感（`--max-linear` / `--max-angular`）
- [ ] 目标点停止精度验证（`stop` 标志在实机上的到位表现）

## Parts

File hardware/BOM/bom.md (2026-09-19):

# Bill of Materials (BOM)

Complete parts list to build one HumanaOpen. Quantities are per robot.

> Work in progress — sections are filled in as the build is completed.

## Cost summary

The control board is optional.

| Section | Subtotal (RMB) |
|---|---|
| Mechanical / structure | 290 |
| 3D printed parts | 300 |
| Motion / actuation | 4,110 |
| Electronics (excl. control board) | 953 |
| Cables / misc | 65 |
| **Total (excl. control board, excl. fasteners)** | **≈ 5,718** |

## Mechanical / structure

### Differential base

| Part / description | Spec / size | Qty | Unit price | Total | Source |
|---|---|-----|---|---|---|
| Caster wheel (differential-drive base) | 5 inch (12.7 cm) | 2 | 33 RMB | 66 RMB | [link](https://e.tb.cn/h.8KjMwtvPCctqYIB?tk=8CsCTTQGr5Y) |
| Swivel caster wheel | Ø25 mm, wheel width 13 mm, base 39 × 33 mm, mounting hole pitch 30 × 24 mm, mounting height 37.5 mm | 2 | 3 RMB | 6 RMB | [link](https://e.tb.cn/h.8KvHhYsMbquYeNy?tk=0FWcTTwToO5) |
| Ball bearing | 6706RS, 30 × 37 × 4 mm | 2 | 11 RMB | 22 RMB | [link](https://e.tb.cn/h.8ppes1EsjZbPZ7G?tk=j67IT6WceLJ) |

### Lift structure

| Part / description | Spec / size | Qty | Unit price | Total | Source |
|---|---|-----|---|---|---|
| Graphite self-lubricating bronze bushing | 8 × 15 × 24 mm | 2 | 6 RMB | 12 RMB | [link](https://e.tb.cn/h.8LyLe0PfJWP7vzO?tk=2RPvT6qeK39) |
| T-leadscrew with brass nut | T8 × 300 mm | 1 | 12 RMB | 12 RMB | [link](https://e.tb.cn/h.8MsdKG0YofaR0MA?tk=FcbUTTjETcR) |
| Bearing (bearing 608-2Z, iron shield) — Japan VBI | 8 × 22 × 7 mm | 1 | 1 RMB | 1 RMB | [link](https://e.tb.cn/h.8KWfffzVtRIZkMB?tk=IkvxT6Jfnwz) |
| Aluminium rigid coupling | Ø20 × 25 mm, bores Ø8 / Ø6 | 1 | 4 RMB | 4 RMB | [link](https://e.tb.cn/h.8K8vuIaWV6FE6xU?tk=vCWeTTQZ5ji) |
| Bus-servo flat-shaft flange (A servo horn) | A-style servo horn | 1 | 12 RMB | 12 RMB | [link](https://e.tb.cn/h.8LBtAQFkrs6S6lb?tk=qVBvTTQV6sU) |
| Hardened precision shaft | Ø8 × 310 mm, hardened | 2 | 3.5 RMB | 7 RMB | — |
| Aluminium extrusion (M6 tapped holes at both ends) | 2040 EU-spec silver, 300 mm | 1 | 10 RMB | 10 RMB | [link](https://e.tb.cn/h.8oH8sbI8ngX3S5c?tk=VQAlTTQObBL) |

### Leader arm

| Part / description | Spec / size | Qty | Unit price | Total | Source |
|---|---|-----|---|---|---|
| Aluminium extrusion | 3060 EU-spec silver | 1 | 30 RMB | 30 RMB | — |
| Aluminium plate | 200 × 300 mm, M6 holes — 116 mm hole spacing along the 200 mm side, 30 mm along the 300 mm side | 1 | 100 RMB | 100 RMB | — |
| Aluminium extrusion corner bracket | 3060, 90° double-slot | 2 | 4 RMB | 8 RMB | [link](https://qr.1688.com/s/aVNYKMW5) |

## 3D printed parts

Filament: **PLA / PETG** (Bambu Lab PLA Basic / Anycubic PLA, or PETG for
stronger structural parts). A large-build-volume printer (e.g. Anycubic Kobra
3 MAX) is required for the large printed parts.

| Part / description | STL file | Qty | Total cost | Notes |
|---|---|-----|---|---|
| PLA / PETG printed parts | [`stl/HumanaOpen_stl/`](../stl/HumanaOpen_stl/) (17 parts), [`stl/Open-arms-mini-stl/`](../stl/Open-arms-mini-stl/) (21 parts) | 6 | ≈ 300 RMB | Requires a large-format printer (Anycubic Kobra 3 MAX) |

## Fasteners

| Part / description | Spec | Qty |
|---|---|-----|
| Chassis servo bracket screws | M3*22 | 8 |
| Chassis caster wheel screws | M3*12 | 8 |
| Drive wheel hub screws | M3*12 | 8 |
| Drive wheel hub washers | M3 | 8 |
| Drive wheel screws | M3*25 | 10 |
| Chassis self-tapping screws | M3*20 (self-tapping) | 32 |
| Lift aluminium extrusion screws | M6*12 (hex socket) | 4 |
| Lift connector screws | M3*10 | 4 |
| Lift base mounting screws | M3*20 (self-tapping) | 4 |
| Lift inner printed part screws | M5*22 | 8–16 |
| Lift outer bearing screws | M4*16 (flat head) | 4 |
| Lift outer bearing nuts | M4 | 4 |
| Arm shoulder screws | M6*20 | 16 |
| Chest RGB camera screws | M2*12 | 4 |
| Body mounting screws | M3*10 (self-tapping) | 4 |
| Neck screws | M3*20 | 2 |
| Head RGB camera screws | M2*10 | 4 |
| Display screws | M3.5*8 | 4 |

## Motion / actuation

| Part / description | Model | Qty | Unit price | Total | Source |
|---|---|-----|---|---|---|
| Follower arm servos (left + right, 8 each) | FEETECH ST3215 C018 | 16 | 110 RMB | 1,760 RMB | [link](https://e.tb.cn/h.8KS047iJugyLfv9?tk=DSDWTTSxLeS) |
| Head servos (pan + tilt) | FEETECH ST3215 C018 | 2 | 110 RMB | 220 RMB | [link](https://e.tb.cn/h.8KS047iJugyLfv9?tk=DSDWTTSxLeS) |
| Lift motor | FEETECH ST3250 | 1 | 310 RMB | 310 RMB | [link](https://e.tb.cn/h.8LwGPtampPRo6fc?tk=uCJATT7aXjl) |
| Base wheel motors (left + right) | FEETECH ST3215 C018 | 2 | 110 RMB | 220 RMB | [link](https://e.tb.cn/h.8KS047iJugyLfv9?tk=DSDWTTSxLeS) |
| Leader arm servos (left + right, 8 each) | FEETECH ST3215 C046 | 16 | 100 RMB | 1,600 RMB | [link](https://e.tb.cn/h.8KS047iJugyLfv9?tk=DSDWTTSxLeS) |

## Electronics

| Part / description | Model / spec | Qty | Unit price | Total | Source |
|---|---|-----|---|---|---|
| Main control board (Host) — optional | Raspberry Pi 5 4GB | 1 | 1,200 RMB | 1,200 RMB | — |
| Main control board (Host) — optional | Jetson Orin Nano Super 8GB | 1 | 3,800 RMB | 3,800 RMB | — |
| Camera (head/left_wrist/right_wrist/chest) | 720P 90° distortion-free USB | 4 | 70 RMB | 280 RMB | [link](https://e.tb.cn/h.8KRXD6pf6IHHQNu?tk=Liq1TT8421C) |
| Follower (from) power supply | 12V 4A | 1 | 20 RMB | 20 RMB | — |
| Leader (master) power supply | 7.3V 3A | 2 | 20 RMB | 40 RMB | — |
| Bus servo driver board | Waveshare (微雪) bus servo driver | 2 | 27 RMB | 54 RMB | [link](https://e.tb.cn/h.8Lya2xQuOF0N34m?tk=HTlUTT8TJLG) |
| Battery | 20000mAh 140W dual Type-C + USB-A | 1 | 399 RMB | 399 RMB | — |
| Display (optional) | 7" touch with case, 1024×600 | 1 | 160 RMB | 160 RMB | [link](https://e.tb.cn/h.8JQRkOZKPsCPwZ7?tk=60rcT7YLj2W) |

## Cables / misc

| Part / description | Spec | Qty | Unit price | Total | Source |
|---|---|-----|---|---|---|
| USB-to-Type-C cable | USB 3.2, 10 Gbps | 2 | 8.5 RMB | 17 RMB | [link](https://e.tb.cn/h.8KRq9s1kJBHLtdN?tk=yS9XTT8GzSZ) |
| Y-split Type-C to DC 5521 cable | 0.5 m | 1 | 20 RMB | 20 RMB | [link](https://e.tb.cn/h.8KRHy0GP3Zk8Rw8?tk=UkoSTT8Dq9k) |
| USB to DC 5521 cable (optional, Raspberry Pi) | 0.5 m | 1 | 7 RMB | 7 RMB | [link](https://e.tb.cn/h.8J9K33ZS7bNSVQz?tk=PukJT71DTRR) |
| Type-C to DC 5521 cable (optional, Jetson) | 0.5 m | 1 | 9 RMB | 9 RMB | [link](https://e.tb.cn/h.8qUeZkgpcKBiZ6R?tk=239sT7cfg4G) |
| Terminal wire | 3P 5264 reverse terminal wire, 1000 mm | 1 | 3 RMB | 3 RMB | [link](https://e.tb.cn/h.8oTllunUw9ECpZp?tk=PRvNT60hcKX) |
| Terminal wire | 3P 5264 reverse terminal wire, 500 mm | 1 | 3 RMB | 3 RMB | [link](https://e.tb.cn/h.8oTllunUw9ECpZp?tk=PRvNT60hcKX) |
| Terminal wire | 3P 5264 reverse terminal wire, 200 mm | 2 | 3 RMB | 6 RMB | [link](https://e.tb.cn/h.8oTllunUw9ECpZp?tk=PRvNT60hcKX) |
| Chest camera cable (optional) | 100 mm | 1 | included with camera | — | — |
| Head camera cable | 300 mm | 1 | included with camera | — | — |
| Wrist camera cable | 900 mm | 2 | included with camera | — | — |

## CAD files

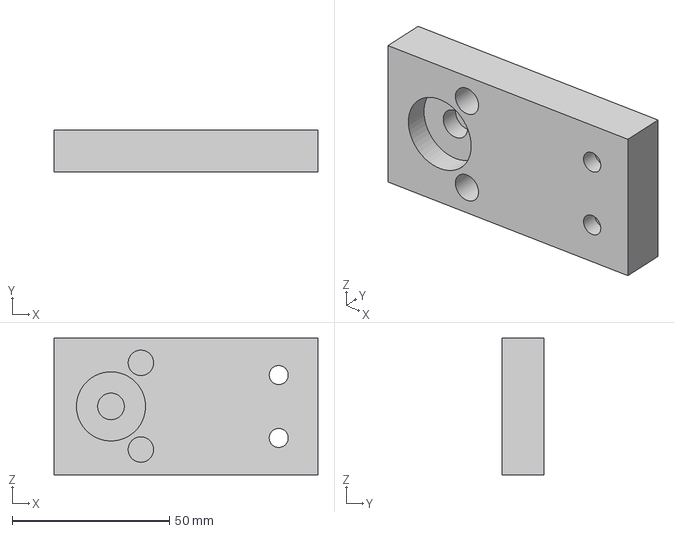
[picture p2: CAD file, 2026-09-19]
hardware/cad/step/HumanaOpen_step/8.LiftTopMount-V1.step
84.0 x 13.5 x 43.5 mm

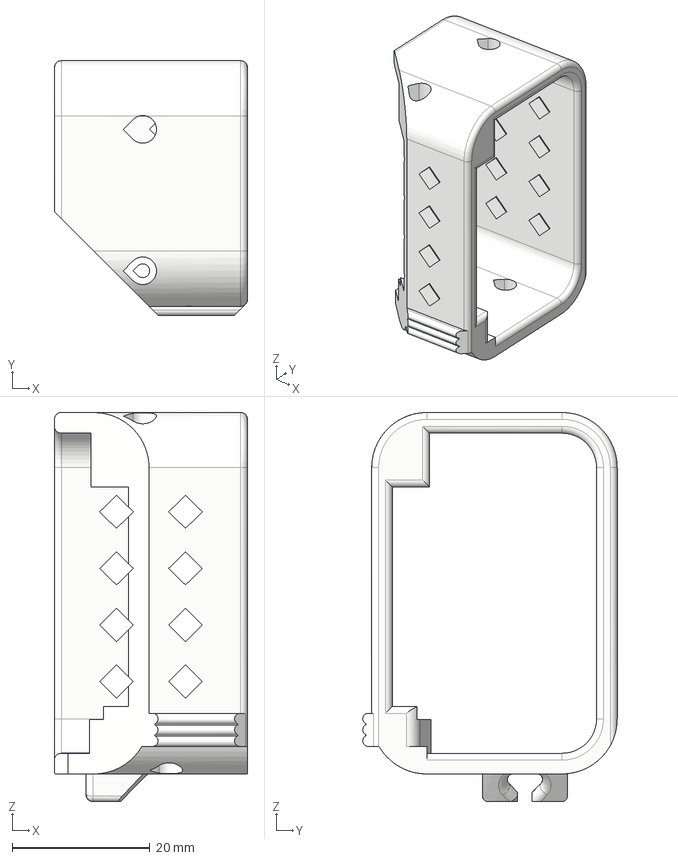
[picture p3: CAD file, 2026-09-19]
hardware/cad/step/Open-arms-mini_step/J4_holder.step
28.0 x 36.9 x 56.4 mm
Wiring_holder v1
Wiring_holder v1 (1)

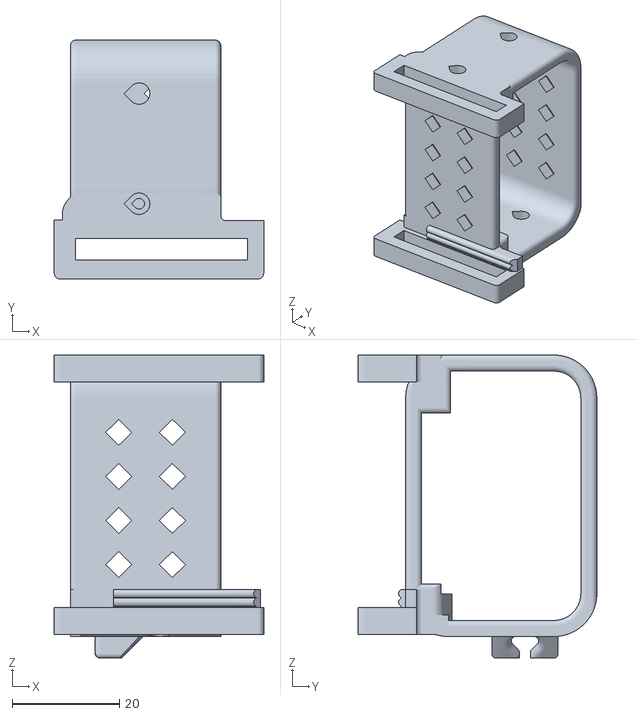
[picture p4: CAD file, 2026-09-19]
hardware/stl/Open-arms-mini-stl/J6 holder with strap v4.stl
39.0 x 44.4 x 56.4

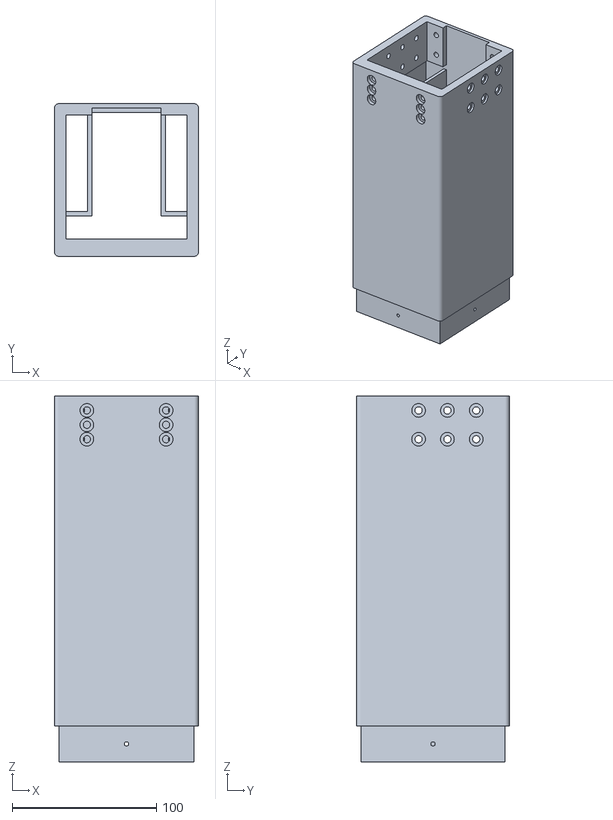
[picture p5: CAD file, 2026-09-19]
hardware/urdf/meshes/9.LiftSlider-V12.stl
100.0 x 106.0 x 254.0

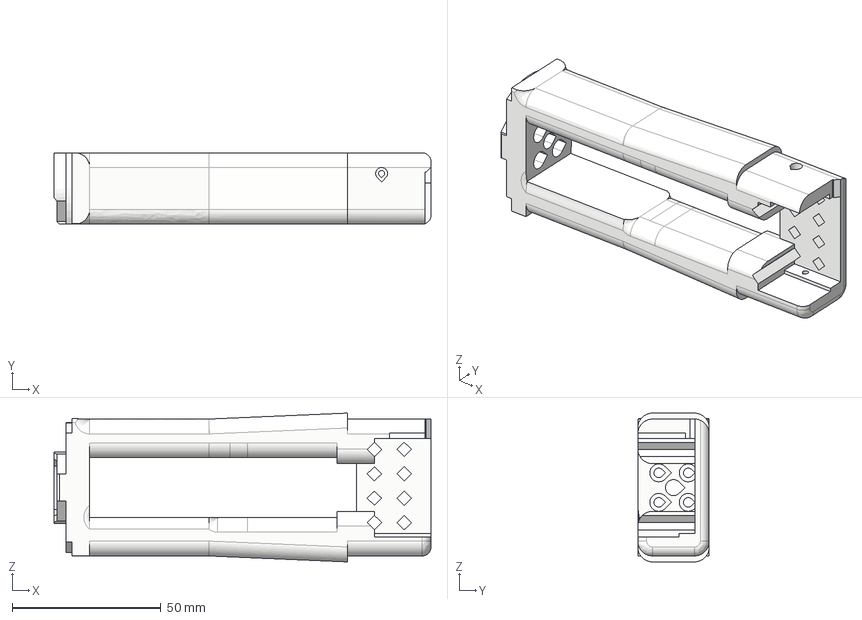
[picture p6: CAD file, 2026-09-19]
hardware/cad/step/Open-arms-mini_step/J4.step
126.6 x 24.0 x 50.0 mm
Wiring_holder v1
Wiring_holder v1 (1)
Wiring_holder v1 (2)
Wiring_holder v1 (1) (1)
Wiring_holder v1 (3)

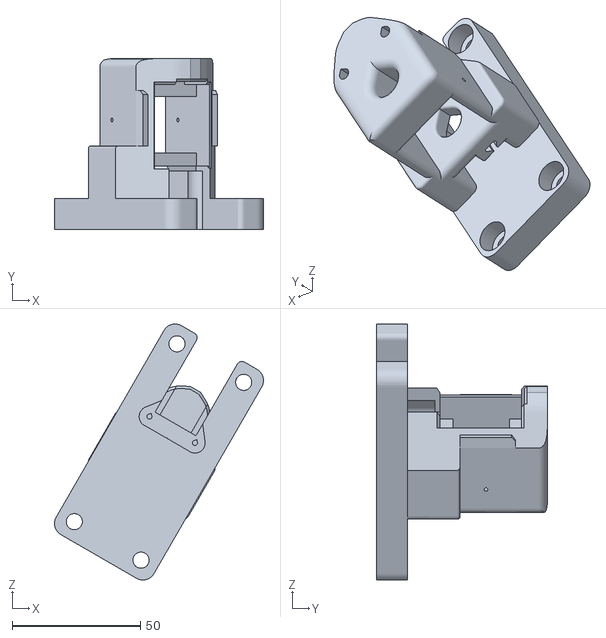
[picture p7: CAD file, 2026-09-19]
hardware/urdf/meshes/J1 v5.stl
81.4 x 66.5 x 99.7

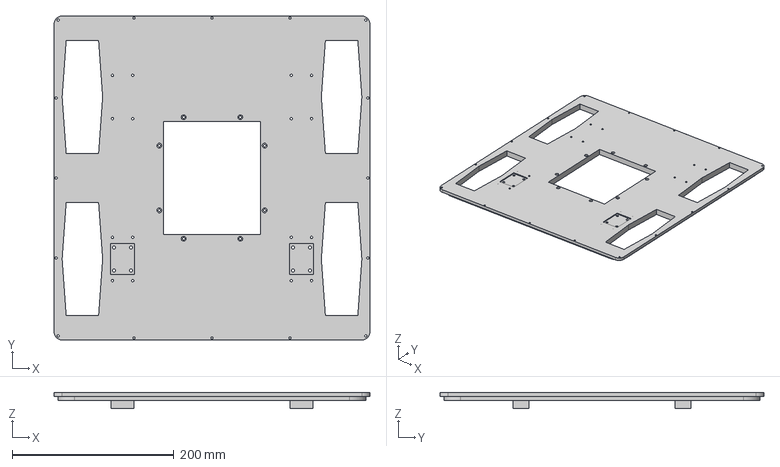
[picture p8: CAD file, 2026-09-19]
hardware/cad/step/HumanaOpen_step/5.LowerBase-V15.step
390.0 x 400.0 x 20.0 mm

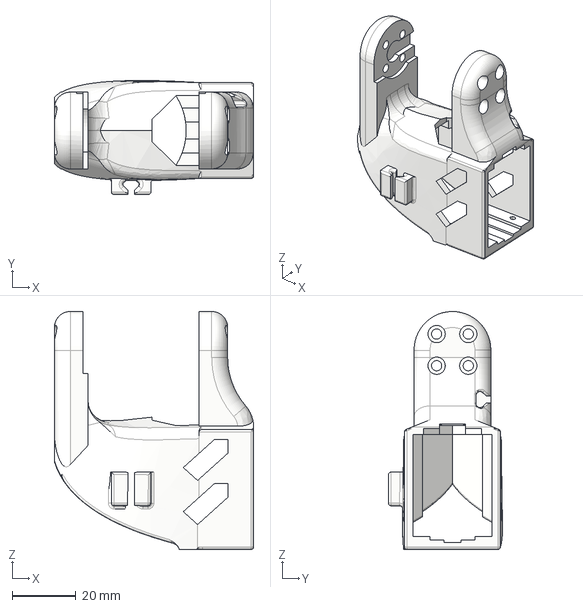
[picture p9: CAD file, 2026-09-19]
hardware/cad/step/Open-arms-mini_step/J5.step
62.3 x 35.6 x 74.4 mm

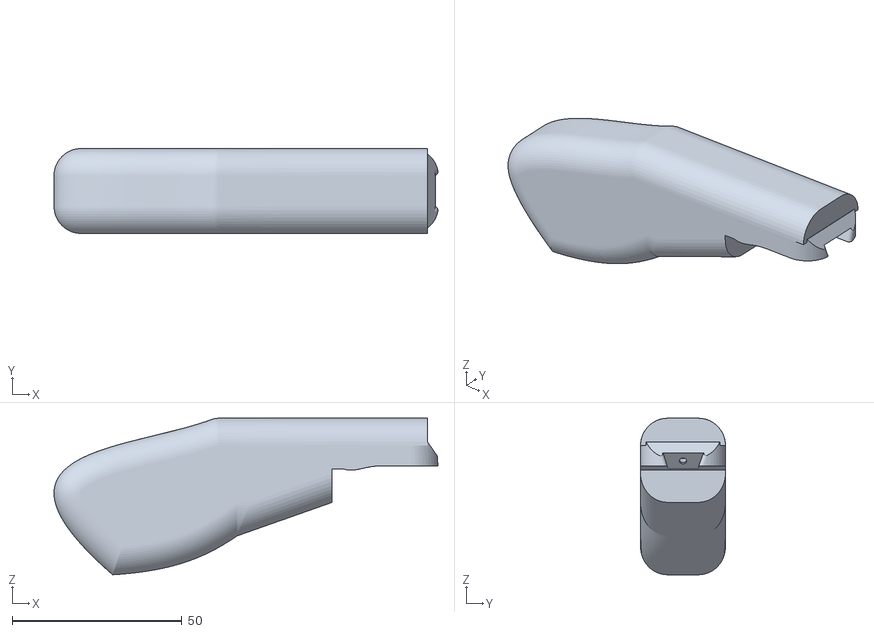
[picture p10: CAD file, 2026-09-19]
hardware/stl/Open-arms-mini-stl/J Handle v12.stl
113.0 x 25.0 x 46.1

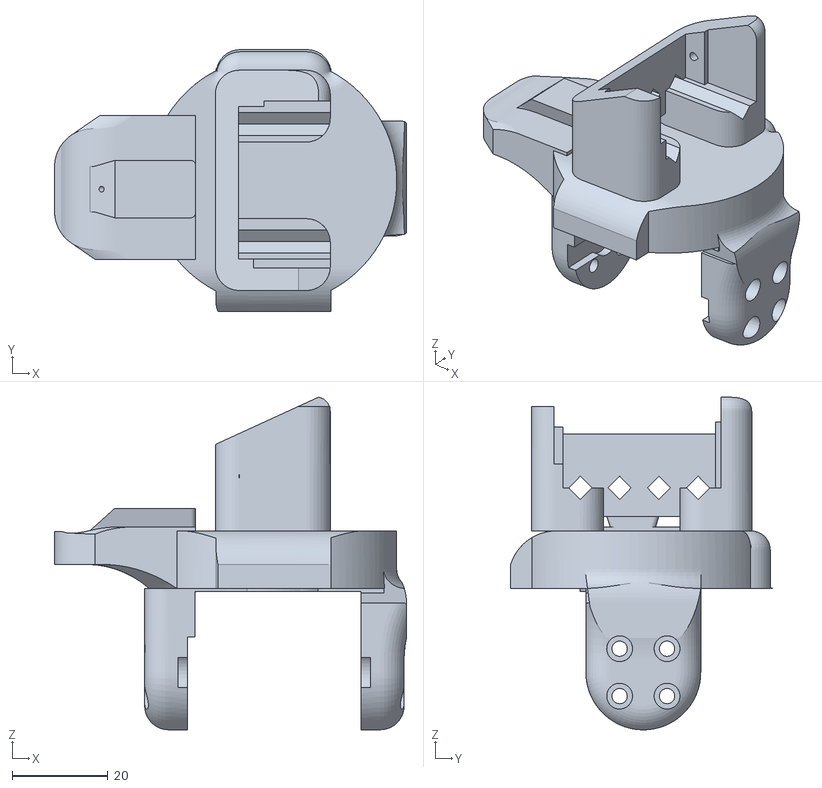
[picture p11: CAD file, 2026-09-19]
hardware/urdf/meshes/J8 L v4.stl
73.5 x 54.7 x 69.5

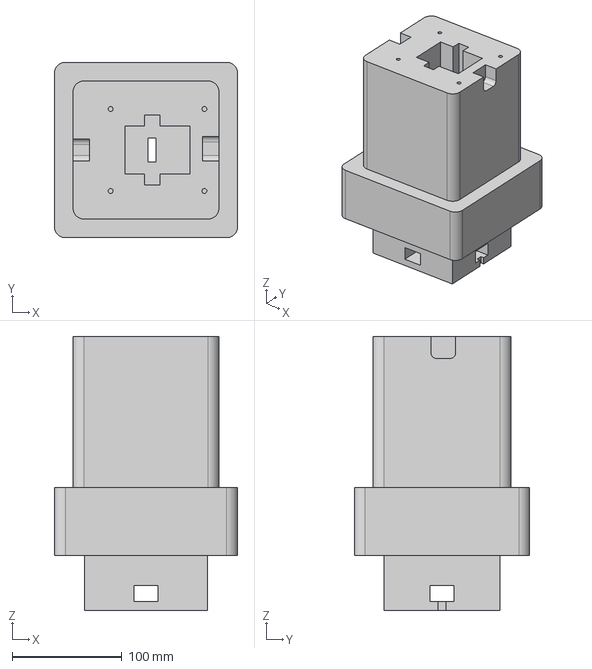
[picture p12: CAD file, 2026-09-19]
hardware/cad/step/HumanaOpen_step/14.LiftBase-V16.step
167.0 x 160.0 x 249.8 mm

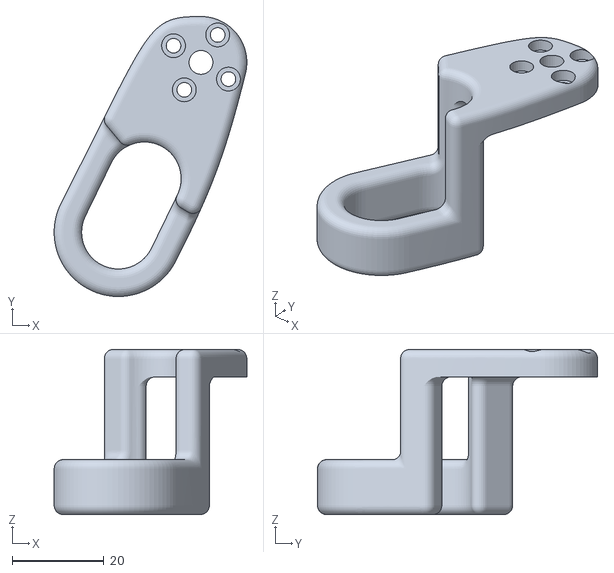
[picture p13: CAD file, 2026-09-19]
hardware/stl/Open-arms-mini-stl/J trigger R v2.stl
42.0 x 61.0 x 36.0

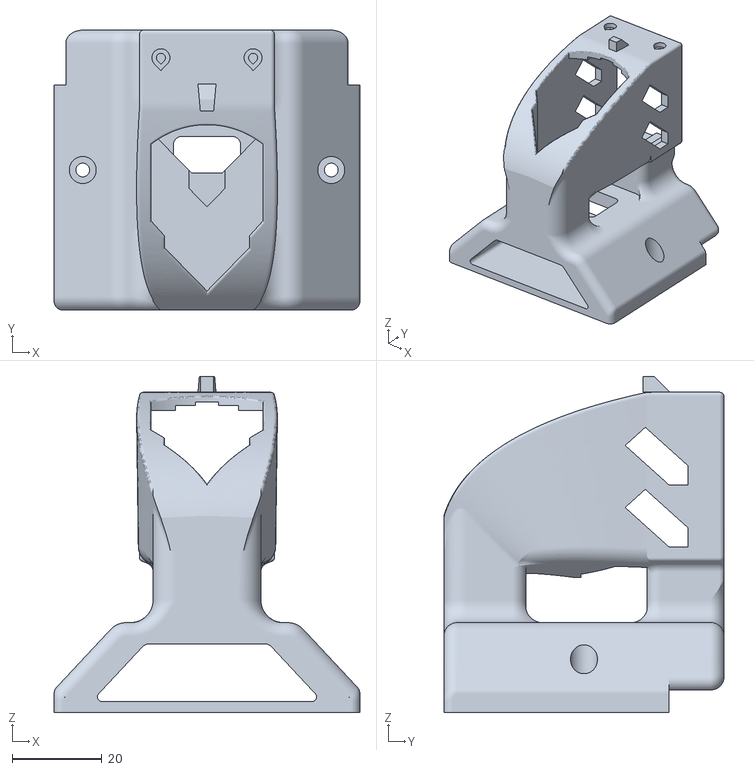
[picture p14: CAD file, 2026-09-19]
hardware/urdf/meshes/12.NeckYaw_V3.stl
68.0 x 62.3 x 74.7

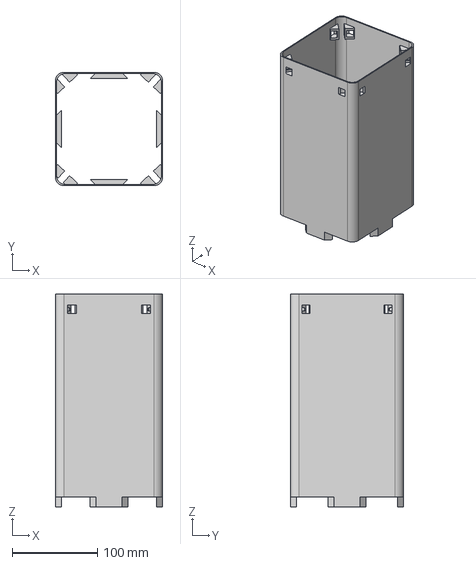
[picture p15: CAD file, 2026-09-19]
hardware/cad/step/HumanaOpen_step/15.Torsor_Housing-V5.step
126.0 x 133.0 x 250.0 mm

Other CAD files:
hardware/cad/step/HumanaOpen_step/9.LiftSlider-V12.step
hardware/stl/Open-arms-mini-stl/J8 holder L v2.stl
hardware/cad/step/Open-arms-mini_step/J Handle.step
hardware/cad/step/Open-arms-mini_step/J8 L.step
hardware/cad/step/HumanaOpen_step/1.GripperFin-V3.step
hardware/cad/step/HumanaOpen_step/10.Torso-V23.step
hardware/cad/step/HumanaOpen_step/11.HeadHousing_V13.step
hardware/cad/step/HumanaOpen_step/12.NeckYaw_V3.step
hardware/cad/step/HumanaOpen_step/13.NeckPitch_V0.step
hardware/cad/step/HumanaOpen_step/16.ChassisServoHolder-V7.step
hardware/cad/step/HumanaOpen_step/2.GripperFinConnector-V2.step
hardware/cad/step/HumanaOpen_step/3.LiftServoMount-V22.step
hardware/cad/step/HumanaOpen_step/4.WheelHub.step
hardware/cad/step/HumanaOpen_step/6.UpperBase-V10.step
hardware/cad/step/HumanaOpen_step/7.LiftSliderConnector-V6.step
hardware/cad/step/Open-arms-mini_step/J trigger L.step
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

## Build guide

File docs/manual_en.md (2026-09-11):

# HumanaOpen Complete Beginner Tutorial

Welcome to HumanaOpen, an open-source semi-humanoid robot built on
[HuggingFace LeRobot](https://github.com/huggingface/lerobot). This tutorial is
written for people who just received the hardware and want to go from "box on
the table" to "robot following learned policies". Every parameter below was
verified against the actual code, and every pitfall in the FAQ is a real
problem we hit and fixed during field testing.

**Hardware overview:**

- **Dual arms**: 2 × 7 DOF + gripper (8× ST3215 C018 servos each)
- **Head**: 2 DOF (2× ST3215 C018 servos)
- **Lift**: Leadscrew-driven (1× **ST3250** servo, T8 leadscrew)
- **Base**: Differential drive (2× ST3215 C018 servos)
- **Cameras**: Head ×1 + left wrist ×1 + right wrist ×1
- **Leader arms** (teleop): 2 × 8 STS3215 C046 servos, run on a separate machine

> This project uses LeRobot **0.4.x**. PyPI has no `lerobot>=1.0` (the latest
> published version is 0.6.x), so HumanaOpen no longer installs lerobot from
> PyPI. You install lerobot from a local source checkout instead, see
> [Section 2](#2-software-installation).

---

## 1. Hardware Setup

### 1.1 Servo Bill of Materials

| Position | Servo | Qty | ID |
|---|---|-----|----|
| Left follower arm J1-J7 + gripper | ST3215 C018 | 8 | 1-8 |
| Right follower arm J1-J7 + gripper | ST3215 C018 | 8 | 1-8 |
| Head Pan / Tilt | ST3215 C018 | 2 | 12, 13 |
| Lift leadscrew | **ST3250** | 1 | **9** |
| Left / Right wheel | ST3215 C018 | 2 | 10, 11 |
| **Left leader arm** J1-J7 + gripper (teleop) | STS3215 C046 | 8 | 1-8 |
| **Right leader arm** J1-J7 + gripper (teleop) | STS3215 C046 | 8 | 1-8 |

⚠️ **Follower servos run at 12V, leader servos at 7.4V.** Do not plug a leader
arm into a 12V board, and do not share a power supply between the two. Each
machine in a dual-machine setup powers its own servos.

### 1.2 Bus Topology

> **Left/right convention**: defined from the robot's own frame of reference.
> Standing behind the robot and facing the same direction as it, the arm on
> your left-hand side is the **left arm** (`port1`), the arm on your right-hand
> side is the **right arm** (`port2`). Wiring decides which physical arm is
> which; the software simply maps `left_arm_*` → `port1` and `right_arm_*` →
> `port2`.

**3-bus mode** (`port3="/dev/ttyACM2"`, the default):

```
Bus 1 ── Left follower arm (1-8) + Head (12,13) ── POSITION mode
Bus 2 ── Right follower arm (1-8) ── POSITION mode
Bus 3 ── Lift (9) + Left wheel (10) + Right wheel (11) ── VELOCITY mode
```

**2-bus mode** (`port3=None`): ⚠️ **this is what the project actually uses
on the test bench**:

```
Bus 1 ── Left follower arm (1-8) + Head (12,13) ── POSITION mode
Bus 2 ── Right follower arm (1-8) + Lift (9) + Wheels (10,11) ── mixed mode
```

In 2-bus mode, bus 2 carries both POSITION-mode servos (right arm) and
VELOCITY-mode servos (lift, wheels). The code handles this fine; each motor
group is written with its own operating mode.

⚠️ **`enable_base=False` disables the wheels *and* the lift.** This is meant
for arms-only bring-up (e.g. before the base is wired). If your wheels or lift
don't respond at all, check that `enable_base` is `True`.

### 1.3 First Connection Sanity Test

Do this right after wiring, before anything else. It verifies the USB buses
and motor power without needing cameras or calibration:

```bash
conda activate lerobot
python3 -c "
from lerobot_robot_humanaopen import HumanaOpen, HumanaOpenConfig
config = HumanaOpenConfig(
    port1='/dev/ttyACM0',   # left arm + head
    port2='/dev/ttyACM1',   # right arm + lift + wheels (2-bus)
    port3=None,
    cameras={},             # skip cameras, motor tests work without them
)
robot = HumanaOpen(config)
robot.connect(calibrate=False)
print('Connected OK')
robot.disconnect()
"
```

What to expect:

- `connect()` opens both buses, then **auto-homes the lift** (drives it down
  until stall, see [Section 9](#9-lift-operation)). Make sure the lift has
  room to travel down and 12V power.
- A warning about missing calibration is **normal** at this stage. See
  [Section 4](#4-calibration) and the FAQ.
- If you only wired the arms (no base, no lift), add `enable_base=False` to
  the config so `connect()` skips the lift entirely.

⚠️ If you already ran calibration before, `connect()` will print
`Press ENTER to restore calibration, or type 'c' to re-calibrate` and **block
waiting for keyboard input**. Interactive use is fine; for scripts, either
answer the prompt or calibrate first.

---

## 2. Software Installation

### 2.1 Create a Conda Environment

Use Python 3.12. A dedicated env avoids conflicts with the system Python.

```bash
conda create -n lerobot python=3.12
conda activate lerobot
```

⚠️ **Always use the lerobot env.** The system `python3` (e.g. conda base,
Python 3.13) often has no `numpy` installed, and the import will fail with a
confusing error. If `python3` from your shell does not say
`(lerobot)` in the prompt, activate the env first.

### 2.2 Install LeRobot from Local Source

As noted above, `lerobot>=1.0` does not exist on PyPI (latest is 0.6.x), and
this project targets the 0.4.x line. We install from a local source checkout:

```bash
pip install -e /home/zach/lerobot-so101-bimanual/lerobot
```

Adjust the path if your checkout lives elsewhere.

### 2.3 Install HumanaOpen

HumanaOpen's `pyproject.toml` deliberately has **no lerobot dependency** (the
locally installed lerobot provides it). Install the package itself with
`--no-deps` so pip does not try to resolve or upgrade lerobot:

```bash
cd /home/zach/HumanaOpen
pip install -e . --no-deps
```

The editable install (`-e`) means any change you make to the HumanaOpen
package takes effect immediately, no reinstall needed.

### 2.4 Verify the Installation (Important!)

```bash
cd /tmp && python -c "import lerobot_robot_humanaopen; print('OK')"
```

⚠️ Run the check **outside** the project directory. If you run it from
`/home/zach/HumanaOpen`, Python automatically adds the current directory to
the import path, so the import can succeed even when the package is not
actually installed. Running from `/tmp` forces a real installed-package check.

Expected output: `OK`.

---

## 3. Servo ID Configuration (First Use Only)

New servos ship with default IDs, so before first use you must burn the
correct IDs. **Connect one servo at a time to the Waveshare board.**

### 3.1 Wiring

- Connect the Waveshare board to the computer via USB
- **Connect only one servo** to the board at a time
- Power the servo (12V supply)

### 3.2 Run Setup

```python
from lerobot_robot_humanaopen import HumanaOpen, HumanaOpenConfig

config = HumanaOpenConfig(port1="/dev/ttyACM0", port2="/dev/ttyACM1")
robot = HumanaOpen(config)

# Prompts you to connect each servo one by one
robot.setup_motors()
```

Follow the prompts: connect the indicated servo, press Enter, wait for the ID
to be written, repeat.

### 3.3 Leader Arm IDs

Leader arm C046 servos also use IDs 1-8 (one set per arm), connected via
another Waveshare board. Use the same `setup_motors()` method with the leader
arm's port.

### 3.4 Scan a Bus for Servos (Debug Tool)

To see which IDs are actually reachable on a bus, use a ping scan. **Call
`bus.connect()` first**, otherwise you get a `'NoneType'` flush error:

```python
from lerobot.motors.feetech import FeetechMotorsBus

bus = FeetechMotorsBus(port="/dev/ttyACM1", motors={})
bus.connect()                 # required before ping!
ids = bus.broadcast_ping()    # returns the set of reachable servo IDs
print("Found servo IDs:", ids)
bus.disconnect()
```

If a servo does not show up, see "Missing motor IDs" in
[Section 11](#11-troubleshooting).

---

## 4. Calibration

Calibration tells the software where each joint's zero and range are. It is
required for the full LeRobot pipeline (record / train / rollout), because
`get_observation()` can only return normalized joint positions once
calibration exists.

### 4.1 What Gets Calibrated

- **Joint servos** (arms, head): half-turn homing + full range recording
- **Wheels**: full continuous rotation range (0-4095)
- **Lift**: stall-detection auto homing (see [Section 9](#9-lift-operation))

### 4.2 Run Calibration

Recommended: use the calibration script (full step hints + post-calibration
verification):

```bash
conda activate lerobot
python3 examples/calibrate_follower.py
```

Or run manually:

```bash
python3 -c "
from lerobot_robot_humanaopen import HumanaOpen, HumanaOpenConfig
robot = HumanaOpen(HumanaOpenConfig(id='follower'))
robot.connect(calibrate=True)
"
```

Interactive flow, step by step:

1. If a calibration file already exists, you are asked:
   `Press ENTER to restore calibration, or type 'c' to re-calibrate`.
   Type `c` to re-calibrate.
2. **Bus 1**: move all left arm and head joints to the **zero pose** (arms
   hanging straight down, gripper closed) → press Enter.
   Then move each joint through its full range of motion → press Enter when
   done. The software records min/max positions per joint.
3. **Bus 2**: repeat for the right arm joints. The gripper gets a dedicated
   closed/open two-point calibration (0=closed, 100=open).
4. Wheels get a full 0-4095 range automatically, no interaction needed.
5. The lift homes automatically via stall detection.

**Zero convention (important)**: the follower and leader both use "**arms
hanging straight down + gripper closed**" as the zero pose. This way
teleoperation maps pose-to-pose (leader hanging → follower hanging), and
during data recording the `action`/`observation` normalization spaces are
physically consistent. When sweeping the ranges, move each joint **symmetrically
around the zero pose** so the range midpoint ≈ the zero pose.

⚠️ Move each joint slowly and through its real physical limits. The recorded
range is what the policy will treat as the full travel, so don't cheat it.

### 4.3 Calibration File Location

**Follower side**: `~/.cache/huggingface/lerobot/calibration/robots/humanaopen/{id}.json`

```
.../humanaopen/follower.json   ← follower calibration (id="follower")
```

The file is loaded automatically on the next `connect()`.

**Leader side** (teleop arms): stored under the teleoperators directory (see
Section 4.4), fully separate from the follower.

### 4.4 Leader (Teleop Arms) Calibration

The leader arms are open-arms-mini (STS3215 C046, 7.4 V), 8 servos per arm
(ID 1-8), with joint names matching the follower. Use the calibration script:

```bash
python3 examples/calibrate_leader.py
```

Per-arm interactive flow (default `calibration_mode="full"`, records real
travel):

1. **Arm hanging straight down + gripper closed** → Enter (sets zero point)
2. **Move each joint through its full travel** → Enter (records real min/max,
   consistent with the follower's normalization space)
3. **Gripper closed position** → Enter
4. **Gripper fully open position** → Enter
5. Calibration saved

**Why record real travel on the leader too?** When recording data for
training, `action` comes from the leader and `observation` from the follower.
If the leader used the full range while the follower records travel, the same
physical pose maps to different normalized values on each side (leader 50 ≠
follower 50), so the model learns a wrong mapping and the follower under/overshoots
at deployment. Recording real travel on the leader aligns both spaces
physically, so **one calibration serves both teleoperation and data
recording — no re-calibration needed**.

> If you only need real-time teleoperation (human compensates live), set
> `calibration_mode="quick"` (joints full range [0,4095], the official
> openarm_mini simplification). But switch back to `"full"` and re-calibrate
> before recording data for training.

Calibration files (separate from the follower, never overwrite):

```
~/.cache/huggingface/lerobot/calibration/teleoperators/humanaopen_leader/leader_left.json
~/.cache/huggingface/lerobot/calibration/teleoperators/humanaopen_leader/leader_right.json
```

Leader implementation (`lerobot_robot_humanaopen/leader.py`):

- `humanaopen_leader`: single-arm teleoperator (`calibration_mode`: `full`/`quick`)
- `bi_humanaopen_leader`: bimanual teleoperator (outputs `left_arm_*` /
  `right_arm_*` prefixed actions)

During teleoperation, `leader.get_action()` produces action keys that match
`follower.send_action()` exactly, so the two connect with zero conversion.

**Direction flips / wrist remap (configurable)**:

The default `flip_joints` / `joint_remap` come from the official openarm_mini
(they encode the direction signature for the *official* leader+follower
pairing). **If your arms are assembled differently from official, some joints
rotate the wrong way and the wrist mapping may be off** — this is
hardware-related, not a bug. Characterize each joint with the diagnostic
script:

```bash
python3 examples/diagnose_teleop.py
```

Then configure per the results:

```python
config = BiHumanaOpenLeaderConfig(
    left_arm_port="/dev/ttyACM2",
    right_arm_port="/dev/ttyACM3",
    flip_joints={"left": ["shoulder_pan", ...], "right": [...]},  # reversed joints
    joint_remap={},  # empty dict if no wrist flex↔yaw swap needed
)
```

The gripper outputs [0,100] directly (0=closed, 100=open), matching the
follower's `RANGE_0_100` — no extra scaling.

⚠️ Leader arms run on 7.4 V (separate from the follower's 12 V); torque is
released during calibration so they can be moved by hand.

### 4.5 "No Calibration Registered" Is Expected Before Calibration

If you call `get_observation()` before calibrating, normalization has no
ranges to work with and the call fails (or returns unusable readings). This is
**normal**, not a bug. Two ways around it:

- Calibrate once (`connect(calibrate=True)`), then use `get_observation()`.
- For lift-only work, skip the full robot class and use the direct lift test,
  see [Section 9.4](#94-lift-axis-test).

---

## 5. Operation Modes

### 5.1 Single Machine Mode (All devices on one computer)

All Waveshare boards and cameras connected to the same machine:

```python
from lerobot_robot_humanaopen import HumanaOpen, HumanaOpenConfig

config = HumanaOpenConfig(
    port1="/dev/ttyACM0",   # left arm + head
    port2="/dev/ttyACM1",   # right arm
    port3="/dev/ttyACM2",   # lift + wheels (3-bus) or None for 2-bus
)
robot = HumanaOpen(config)
robot.connect()

# Read observation
obs = robot.get_observation()
print(obs.keys())

# Hold current position: copy .pos keys, stop base and lift
action = {k: obs[k] for k in obs if k.endswith(".pos")}
action["x.vel"] = 0.0
action["theta.vel"] = 0.0
action["lift_axis.height_mm"] = obs.get("lift_axis.height_mm", 0)
robot.send_action(action)

robot.disconnect()
```

Observation keys: one `.pos` per arm/head joint, plus `x.vel`, `theta.vel`,
`lift_axis.height_mm`, optionally `lift_axis.vel`, plus one entry per camera.

Ready-made examples:

```bash
# Single machine loop (read observation, hold position)
python3 examples/single_machine.py

# Keyboard teleoperation of base + lift (needs the `keyboard` package)
python3 examples/teleop_keyboard.py
```

### 5.2 Keyboard Teleop Keymap

From `teleop_keys` in the config (`teleop_keyboard.py`):

| Key | Action |
|-----|---|
| `i` | Forward |
| `k` | Backward |
| `j` | Rotate left |
| `l` | Rotate right |
| `n` | Speed up |
| `m` | Speed down |
| `u` | Lift up |
| **`h`** | **Lift down** ⚠️ (project-specific: it is `h`, **not** `d`) |
| `b` | Quit |

⚠️ **Lift down is `h`, not `d`.** This is a deliberate project modification.
Muscle-memory from other robots will make you press `d` and nothing happens.

### 5.3 Dual-machine ZMQ Mode

**Robot side (Jetson / Raspberry Pi):**

```bash
python3 -c "
from lerobot_robot_humanaopen import HumanaOpenConfig
from lerobot_robot_humanaopen.humanaopen_host import HumanaOpenHost

host = HumanaOpenHost(HumanaOpenConfig())
host.run()
"
```

Default ZMQ ports: observations 5556 / commands 5555.

**Teleop side (Laptop):**

```python
from lerobot_robot_humanaopen.humanaopen_client import HumanaOpenClient
from lerobot_robot_humanaopen import HumanaOpenClientConfig

client = HumanaOpenClient(
    HumanaOpenClientConfig(remote_ip="192.168.1.100")  # Robot IP
)
client.connect()

obs = client.get_observation()
# Connect leader arms or keyboard teleop here
# ...

client.send_action(action)
client.disconnect()
```

### 5.4 Arms-Only Mode

During bring-up, before the base is wired:

```python
config = HumanaOpenConfig(
    port1="/dev/ttyACM0",
    port2="/dev/ttyACM1",
    port3=None,
    enable_base=False,   # wheels AND lift are disabled
    cameras={},
)
```

With `enable_base=False`, the lift and wheel motors are never attached to any
bus, so bring-up of the arms won't touch them. Full observation keys that
depend on the base/lift are not available in this mode.

### 5.5 Keyboard Permissions & Base Test

**Keyboard library choice (Linux must-read)**

Two keyboard libraries with different permission requirements:

- **`pynput` (recommended)**: works **without root** on a desktop X11 session.
  Requires `DISPLAY` to be set (a desktop terminal has it by default).
- **`keyboard`**: **hard-requires root** on Linux (`ensure_root()` check);
  adding yourself to the `input` group does not help. Either run with `sudo`
  or switch to pynput.

```bash
# Install pynput
pip install pynput
```

**Base-only keyboard test**

A keyboard script that drives only the base, never touching arms or lift (no
calibration required):

```bash
python3 examples/test_base_keyboard.py
```

Keys: `i`/`k` forward/backward, `j`/`l` rotate left/right, `n`/`m` speed up/down
(3 levels: 0.05/0.10/0.20 m/s), `b` quit. Hold to move, release to stop.

> ⚠️ Lift the robot off the ground (wheels in the air) when testing base
> direction; if testing on the ground, make sure the area is clear.

> If you use the `keyboard` library and need `sudo`:
> `sudo /home/zach/miniconda3/envs/lerobot/bin/python examples/test_base_keyboard.py`
> (must use the full conda python path, otherwise sudo uses the system python
> and won't find the packages).

**Base direction fix (wheel mounted mirrored)**

If pressing `i` (forward) actually spins the robot in place, and `j` (rotate
left) drives it forward, one wheel is **mounted mirrored** (positive raw
velocity drives it backward). The differential command then makes the two
wheels counter-rotate, which reads as forward/rotate being swapped.

Fix: set the mirrored wheel to `-1` in the config:

```python
config = HumanaOpenConfig(
    ...
    wheel_dir_signs={
        "base_left_wheel": -1,   # left wheel mirrored → invert
        "base_right_wheel": 1,   # right wheel OK
    },
)
```

`+1` = positive raw velocity drives the wheel forward; `-1` = wheel is
mirrored. The sign is applied on both the command path
(`_body_to_wheel_raw`) and the feedback path (`_wheel_raw_to_body`) so the
body-frame estimate stays consistent. To tell which wheel is mirrored: press
`i`; if the robot turns left, the left wheel is mirrored; right, the right
wheel.

**Skipping lift homing**

`connect()` auto-homes the lift by default. When testing other subsystems and
the lift is at a known position, skip it:

```python
config = HumanaOpenConfig(
    port1="/dev/ttyACM0",
    port2="/dev/ttyACM1",
    port3=None,
    cameras={},
    home_lift_on_connect=False,   # skip automatic lift homing
)
```

The lift is then only registered and configured (it never moves).

---

## 6. Data Collection

### 6.1 Using lerobot-record

```bash
conda activate lerobot
lerobot-record \
    --robot.type=humanaopen \
    --robot.port1=/dev/ttyACM0 \
    --robot.port2=/dev/ttyACM1 \
    --robot.port3=/dev/ttyACM2 \
    --robot.cameras='{"head": {"type": "opencv", "index_or_path": "/dev/video0", "fps": 30, "width": 640, "height": 480}, "left_wrist": {"type": "opencv", "index_or_path": "/dev/video2", "fps": 30, "width": 640, "height": 480}, "right_wrist": {"type": "opencv", "index_or_path": "/dev/video4", "fps": 30, "width": 640, "height": 480}}' \
    --teleop.type=openarm_mini \
    --teleop.port=/dev/ttyACM_leader \
    --dataset.repo_id=your_name/my_humanaopen_data \
    --dataset.num_episodes=10 \
    --dataset.single_task="describe your task"
```

For a **2-bus** machine (what this project runs on the bench), just drop the
`--robot.port3` argument:

```bash
lerobot-record \
    --robot.type=humanaopen \
    --robot.port1=/dev/ttyACM0 \
    --robot.port2=/dev/ttyACM1 \
    --robot.cameras='{...same as above...}' \
    --teleop.type=openarm_mini \
    --teleop.port=/dev/ttyACM_leader \
    --dataset.repo_id=your_name/my_humanaopen_data \
    --dataset.num_episodes=10 \
    --dataset.single_task="describe your task"
```

### 6.2 Finding Camera Indices

The default camera config in the code uses `/dev/video0` (head),
`/dev/video2` (left wrist) and `/dev/video4` (right wrist). To enumerate what
is actually present on your machine:

```bash
lerobot-find-cameras opencv
```

Adjust `index_or_path` in the `--robot.cameras` argument (or in
`default_cameras()` inside `config_humanaopen.py`) to match. ⚠️ **Use the same
camera names and resolutions for collection, training and deployment.** The
pipeline keys observations by camera name, so `head` during recording must be
`head` during rollout.

### 6.3 Dual-machine ZMQ Data Collection

**Robot side:**

```bash
python3 -c "
from lerobot_robot_humanaopen import HumanaOpenConfig
from lerobot_robot_humanaopen.humanaopen_host import HumanaOpenHost
HumanaOpenHost(HumanaOpenConfig()).run()
"
```

**Teleop side:** run the recording script connected to the ZMQ stream.
Observations come from the robot; actions come from the leader arms connected
to the laptop.

---

## 7. Model Training

After data collection, training runs on any machine (even one without the
robot attached):

```bash
conda activate lerobot
lerobot-train \
    --policy.type=act \
    --dataset.repo_id=your_name/my_humanaopen_data \
    --output_dir=./outputs
```

Override training parameters via CLI:

```bash
lerobot-train --policy.type=act --dataset.repo_id=... \
    --training.batch_size=32 --training.epochs=100
```

**Supported policies**: `act`, `diffusion`, `smolvla`, `pi0`, `pi05`,
`groot`, and more. The dataset format is shared, so switching policies is just
changing `--policy.type` and retraining.

---

## 8. Model Deployment (Inference)

### 8.1 Single Machine

```bash
conda activate lerobot
lerobot-rollout \
    --policy.path=./outputs/checkpoints/last \
    --robot.type=humanaopen \
    --robot.port1=/dev/ttyACM0 \
    --robot.port2=/dev/ttyACM1 \
    --robot.port3=/dev/ttyACM2
```

⚠️ Before rollout, make sure the robot is calibrated (Section 4) and the
cameras are connected. Rollout sends learned actions directly to the hardware,
so keep a hand on the power switch and keep the emergency stop in mind
([Section 9.5](#95-emergency-stop-ctrl-c-does-not-stop-the-lift)).

### 8.2 Dual-machine ZMQ Inference

**Robot side runs the ZMQ host, teleop side loads the policy:**

```bash
# Robot side
python3 -c "
from lerobot_robot_humanaopen import HumanaOpenConfig
from lerobot_robot_humanaopen.humanaopen_host import HumanaOpenHost
HumanaOpenHost(HumanaOpenConfig()).run()
"
```

The teleop side needs a custom script that loads the policy and sends the
resulting actions through the ZMQ client.

---

## 9. Lift Operation

The lift is a **ST3250** servo (ID 9) driving a **T8 leadscrew** (8.0 mm lead
per revolution) through a **direct drive** (`belt_ratio=1.0`, there is no
timing belt in the current build). Total travel is **300 mm** (`soft_max_mm`).

### 9.1 How connect() Homes the Lift

Every `connect()` call auto-homes the lift:

1. Drive **down** at `home_down_speed=1500` (raw velocity units).
2. Stop on stall, detected by a **dual safety** condition:
   - `Present_Current` exceeds `home_stall_current_ma=200`, **or**
   - the encoder position stops changing (position freeze).
   Two consecutive stall observations end homing.
3. Back off **5°** upward (`home_backoff_deg`) to relieve gear stress.
4. Record the current position as height zero.
5. Restore **VELOCITY mode + torque** automatically. The lift is now ready to
   control, no manual mode switching needed.

### 9.2 Height Control (recommended)

```python
# Read current height (mm, relative to homed zero)
height = obs["lift_axis.height_mm"]

# Set a target height (mm)
action["lift_axis.height_mm"] = 200.0
```

The lift runs a P controller in software:
`velocity = kp_vel * (target_height - current_height)`, clamped to `±v_max`.
With `kp_vel=500` and `on_target_mm=1`, it is considered "at target" when the
error is within 1 mm.

### 9.3 Direct Velocity Control

```python
action["lift_axis.vel"] = 500  # raw velocity units, positive=up, negative=down
```

### 9.4 Safety Guards

- **Descent floor**: `descent_floor_mm=3` is a hard guard. Downward commands
  are refused once height ≤ 3 mm. ⚠️ **Test targets must never go below 3 mm.**
- **Soft limits**: motion is blocked outside `soft_min_mm=0` … `soft_max_mm=280` (280mm leaves a 20mm mechanical safety margin on the 300mm leadscrew travel, so inertial overshoot can't hard-hit the mechanical top).
- **Stall detection**: homing stops automatically via current + freeze checks.

### 9.5 Emergency Stop: Ctrl+C Does NOT Stop the Lift ⚠️

Servos are hardware. Once the lift receives a velocity command, it keeps
spinning even if the Python process exits. Killing the script with Ctrl+C
alone **will not stop the lift**. Any script that commands the lift must handle
`KeyboardInterrupt` (or use `try/finally`) and explicitly write:

```python
bus.write("Goal_Velocity", "lift_axis", 0)
bus.write("Torque_Enable", "lift_axis", 0)
```

The example script below already does this. If you write your own scripts,
copy that pattern.

### 9.6 Lift Axis Test

Validate the lift hardware and software without arms, wheels or cameras:

```bash
conda activate lerobot
cd /home/zach/HumanaOpen
python3 examples/test_lift_only.py
```

**Flow**: connect (only the lift motor, ID 9 on `/dev/ttyACM1`) → auto home
downward (stops on stall) → raise 50 mm → lower to 3 mm (the descent floor).

- ⚠️ **Safety**: the script handles Ctrl+C (writes `Goal_Velocity=0` +
  `Torque_Enable=0`, see Section 9.5).
- **Prerequisite**: lift servo (ID 9) wired on bus2 (`/dev/ttyACM1`), 12V
  powered.
- **Not needed**: arms, wheels, cameras, calibration. This test bypasses the
  full robot class and drives the motor directly, so it works before any
  calibration exists.

### 9.7 Velocity Unit Mismatch (Check Your Servo!)

The ST3250 velocity unit is set by the **Phase register (address 18), BIT2**:

| BIT2 | Velocity unit | Notes |
|---|---|---|
| `0` | 0.732 RPM/raw | factory-style default, coarse |
| `1` | 0.0146 RPM/raw | fine-grained, **measured on this bench** |

The `v_max=3853` default in the code was tuned for **BIT2=1**
(0.0146 RPM/raw) and gives roughly **7.5 mm/s** (300 mm travel ≈ 40 s).

- If you assume the 0.732 unit, the equivalent `v_max` is about **77**. Using
  such a small value makes the lift barely move.
- A very large `v_max` value makes the lift shoot to full speed and overshoot.

To confirm **your** servo's unit before trusting the numbers:

```bash
python3 examples/check_phase.py
```

It reads the Phase register, prints BIT2, and tells you the matching `v_max`.
If your servo reports BIT2=0, set `v_max` accordingly (see
[Section 10.2](#102-liftaxisconfig)).

---

## 10. Configuration Reference

All values below are copied from the code. If the manual and the code ever
disagree, **the code wins**.

### 10.1 HumanaOpenConfig

| Parameter | Default | Description |
|---|---|---|
| `port1` | `/dev/ttyACM0` | Left arm + head bus port |
| `port2` | `/dev/ttyACM1` | Right arm bus port |
| `port3` | `/dev/ttyACM2` | Lift + wheels bus port (`None` = 2-bus mode) |
| `enable_base` | `True` | `False` = arms-only testing; wheels and lift are auto-disabled |
| `home_lift_on_connect` | `True` | `False` = skip the automatic lift homing in `connect()` (when testing other subsystems) |
| `disable_torque_on_disconnect` | `True` | Release torque on all servos at `disconnect()` |
| `max_relative_target` | `None` | Clamp per-step position changes (degrees or %); `None` = no clamp |
| `use_degrees` | `False` | Normalize joints in degrees vs the `-100..100` range |
| `cameras` | 3 × OpenCV | `head` = `/dev/video0`, `left_wrist` = `/dev/video2`, `right_wrist` = `/dev/video4` |
| `wheel_radius` | `0.0635` m | Wheel radius (127 mm wheel diameter) |
| `wheelbase` | `0.30` m | Distance between wheels |
| `max_wheel_raw` | `3000` | Max wheel velocity raw value |
| `wheel_dir_signs` | both `+1` | Wheel direction signs; set `-1` for a mirrored wheel (see 5.5) |
| `lift` | `LiftAxisConfig()` | Lift axis configuration (see 10.2) |
| `teleop_keys` | keymap | Keyboard teleop keys (see 10.3) |

### 10.2 LiftAxisConfig

| Parameter | Default | Description |
|---|---|---|
| `enabled` | `True` | Set `False` to disable the lift entirely |
| `name` | `"lift_axis"` | Motor name used as key on the bus |
| `motor_id` | `9` | Lift servo ID |
| `motor_model` | `"sts3250"` | Lift servo model (ST3250) |
| `lead_mm_per_rev` | `8.0` | Leadscrew travel in mm per output-shaft revolution (T8) |
| `belt_ratio` | `1.0` | Leadscrew revs per motor rev; `1` = direct drive, no belt |
| `soft_min_mm` | `0.0` | Software lower limit (mm) |
| `soft_max_mm` | `280.0` | Software upper limit (mm; 20mm safety margin on the 300mm travel) |
| `descent_floor_mm` | `3.0` | Hard guard; downward commands refused at or below this |
| `home_down_speed` | `1500` | Velocity command while homing downward (raw units) |
| `home_stall_current_ma` | `200` | Stall current threshold in mA |
| `home_backoff_deg` | `5.0` | Back off this many degrees after stall |
| `kp_vel` | `500.0` | P gain: `v_cmd = kp_vel * error_mm` |
| `v_max` | `3853` | Max absolute velocity command; ≈7.5 mm/s at BIT2=1 unit |
| `on_target_mm` | `1.0` | Deadband: "at target" when error ≤ 1 mm |
| `dir_sign` | `1` | `+1` = positive velocity raises the lift |

### 10.3 Keyboard Teleop Keymap (`teleop_keys`)

| Key | Action |
|-----|---|
| `i` / `k` | Forward / Backward |
| `j` / `l` | Rotate left / Rotate right |
| `n` / `m` | Speed up / Speed down |
| `u` / **`h`** | Lift up / **Lift down** ⚠️ (`h`, not `d`) |
| `b` | Quit |

### 10.4 Host / Client Configs

| Config | Key fields | Defaults |
|---|---|---|
| `HumanaOpenHostConfig` | `port_zmq_cmd` / `port_zmq_observations` | 5555 / 5556 |
| `HumanaOpenClientConfig` | `remote_ip` | `127.0.0.1` |

---

## 11. Troubleshooting (Real Field Experience)

### Q: "Missing motor IDs" error

**Symptoms**: `connect()` fails because some servos are not found on a bus.

**Causes**:

1. **Daisy-chain break**: servos are chained bus-to-bus. A single broken wire
   or loose connector (e.g. between servo 6 and 7) makes servo 7 and everything
   after it unreachable.
2. **IDs not burned**: new servos still have factory/default IDs.

**Fix**: run the bus scan from [Section 3.4](#34-scan-a-bus-for-servos-debug-tool)
on each bus to see exactly which IDs respond. Then either fix the wiring or
run `setup_motors()`.

### Q: Device port (/dev/ttyACM0) changes after power cycle

**Symptom**: `connect()` fails with "port not found", or the arms are swapped
(left on the right bus).

**Explanation**: after power-cycling, Linux may reassign `ttyACM0`/`ttyACM1`
to different boards, and the two ports effectively swap.

**Fix**: confirm by serial number before connecting:

```bash
ls -l /dev/serial/by-id/
```

Then either update the ports in your config, or create udev symlinks:

```bash
# /etc/udev/rules.d/99-waveshare.rules
SUBSYSTEM=="tty", ATTRS{idVendor}=="1a86", ATTRS{serial}=="A1", SYMLINK+="tty_left_arm"
SUBSYSTEM=="tty", ATTRS{idVendor}=="1a86", ATTRS{serial}=="A2", SYMLINK+="tty_right_arm"
SUBSYSTEM=="tty", ATTRS{idVendor}=="1a86", ATTRS{serial}=="A3", SYMLINK+="tty_base"
```

Then use `/dev/tty_left_arm` etc. in your config.

### Q: "No calibration registered" when reading observations

**Symptom**: `get_observation()` fails before any calibration has been run.

**Explanation**: this is **expected**. Without calibration there are no
min/max ranges, so the bus cannot normalize raw positions into usable joint
values. It is not a hardware fault.

**Fix**: run calibration once (`connect(calibrate=True)`, Section 4). For
lift-only work that does not need calibration at all, use
`examples/test_lift_only.py`, which drives the lift motor directly and reads
`get_height_mm()` instead of `get_observation()`.

### Q: Lift does not move at all

Check, in order:

1. **Power**: the lift servo needs 12V. No power = no motion, no errors.
2. **Bus**: is the lift on the bus the config expects? In 2-bus mode
   (`port3=None`) it is on bus2 (`/dev/ttyACM1`). Wrong port = unreachable.
3. **enable_base**: with `enable_base=False` the lift is not attached at all.
4. **Mode and torque**: the lift must be in **VELOCITY** operating mode with
   **torque enabled**. `home()` restores both automatically; if you disabled
   torque manually, re-enable it. A position command while in velocity mode
   (or vice versa) does nothing useful.
5. **Command clamped**: if height is at the descent floor (≤ 3 mm) or the soft
   limits, downward/upward commands are refused by design. The lift is not
   broken, it is being guarded.

### Q: Lift moves, but way too slow or barely at all

**Cause**: velocity unit mismatch. The Phase register (address 18) BIT2 sets
the ST3250's velocity unit (Section 9.2). All speed constants in this repo are
tuned for **BIT2=0** (50 step/s/raw, `v_max=110` ≈ 8.7 mm/s). A servo that is
still at BIT2=1 (1 step/s/raw, factory default) makes every command run ~50x
slower — the lift "creeps" and looks dead.

**Fix**: modern code switches BIT2 to 0 automatically in
`lift_axis.configure()`. If it still creeps, confirm manually:

```bash
python3 examples/check_phase.py          # report current BIT2
python3 examples/switch_phase_bit2.py    # switch BIT2 → 0
```

**After replacing the lift servo (important)**: a new servo ships with
BIT2=1, and the old `~/.cache/humanaopen/lift_zero.json` holds the previous
motor's encoder data — both need handling:

```bash
rm ~/.cache/humanaopen/lift_zero.json          # stale zero from old motor
python3 examples/check_phase.py                # confirm speed unit
python3 examples/switch_phase_bit2.py          # switch BIT2 → 0
# Normal startup then auto-validates (Model_Number + triangle-consistency
# checks detect the swapped motor and force a re-home — no manual rm needed
# going forward)
```

### Q: Lift overshoots or slams to full speed

**Cause**: `v_max` larger than what the actual velocity unit supports. With
the old-style value the servo hits full speed for the slightest height error
and overshoots the target badly.

**Fix**: the repo is tuned for **BIT2=0** with `v_max=110`. If you hand-edited
`v_max` for BIT2=1 (e.g. 3853) while the code auto-switches to BIT2=0, commands
explode 50x over target. Revert to `v_max=110`, or set what `check_phase.py`
reports for your servo. If overshoot persists, lower `kp_vel` (the P gain maps
height error to velocity) so approach slows down near the target.

### Q: Ctrl+C does not stop the lift

**Symptom**: you kill the script but the lift keeps going.

**Explanation**: servos are hardware. Once they receive a velocity command
they keep spinning; exiting Python does not stop them.

**Fix**: your script must catch `KeyboardInterrupt` (or use `try/finally`) and
explicitly write `Goal_Velocity=0` and `Torque_Enable=0` to the lift motor,
exactly like `examples/test_lift_only.py` does.

### Q: Pressing `d` does not lower the lift

**Answer**: lift down is **`h`**, not `d`. This is a deliberate project
modification (see `teleop_keys`). Use `u`/`h` for lift up/down.

### Q: Camera not found

**Fix**: check `/dev/video*` exists, then run
`lerobot-find-cameras opencv` to enumerate the real device indices. Update
`index_or_path` in your camera configs (`default_cameras()` or the
`--robot.cameras` argument). Keep names consistent across collect/train/deploy.

### Q: How to set servo IDs?

Use `robot.setup_motors()`. Connect one servo at a time to the Waveshare board
and follow the prompts (Section 3).

### Q: Different voltages for leader and follower?

Leader C046 servos run at 7.4V, follower C018 at 12V, with separate power
supplies. In ZMQ dual-machine mode each machine powers its own servos. In
single-machine mode use two power supplies for the two Waveshare boards.

### Q: Does `pip install -e /home/zach/HumanaOpen` without `--no-deps` work?

No. HumanaOpen deliberately declares no lerobot dependency, so `--no-deps` is
required to avoid pip resolving/upgrading anything. And remember to verify the
import from `/tmp` (Section 2.4), not from inside the repo.

### Q: Dual-machine (ZMQ) teleop laggy / follower lags leader?

A: Latency = physical link + control-loop rate + code overhead. Debug from the
bottom up:

**1. Physical layer (check first — most common).** Weak WiFi signal on either
end causes latency spikes:
```bash
iw dev <iface> link | grep signal     # target > -60dBm; -70 to -80 gives 100ms+ spikes
# -79dBm measured: degraded from "occasional 200ms spikes" to "19-second freezes"
# (TCP retransmission storm)
```
- **Fix weak signal**: seat/replace the M.2 antenna (Jetson Orin's default small
  ceramic antenna has low gain; an external stick antenna gains 20dB+), move
  closer to the router, use the 5GHz band.
- Measured: at -79dBm RTT swung to 19s; after fitting the antenna (-59dBm) RTT
  stabilized at 18-36ms.
- If spikes remain at good signal, disable WiFi power-save + periodic scanning:
```bash
sudo iw dev <iface> set power_save off
sudo killall -STOP NetworkManager   # Tegra/Nexus boards scan periodically → ~3s spikes
```

**2. Proxy does NOT affect ZMQ (skippable).** ZMQ is raw TCP — it **never reads**
`http_proxy`/`all_proxy` env vars (libzmq source has zero references; only the
explicit `ZMQ_SOCKS_PROXY` option applies). System-proxy mode cannot hijack
ports 5555/5556; only Clash **TUN mode** (virtual NIC) can. Confirm no TUN:
```bash
ip link show | grep -iE 'utun|tun|meta|mihomo'   # no output = proxy does not affect teleop
```

**3. Control-loop rate.** At 30Hz each end waits a full frame (33ms); the 2-frame
pipeline delay is ~66ms. 60Hz is supported:
```bash
# Host already defaults to 60Hz (max_loop_freq_hz=60)
# Match the teleop side with --fps=60:
python3 examples/teleop_leader_to_follower.py --remote_ip=192.168.1.9 --fps=60
```
- At 60Hz theoretical delay halves (→ ~33ms); host worst serial frame 8ms, teleop
  side 1.7ms — ample headroom.
- If the host logs "worst frame > 17ms" (60Hz budget), the serial bus is busy —
  drop to 30Hz or inspect the bus.

**4. Read the REAL latency.** The status line `rtt:` is **skew-free** round-trip
(the client stamps each command with its perf timestamp, the host echoes it, and
the client computes RTT on its own monotonic clock — immune to wall-clock skew).
Typical values:
- `18ms` = 60Hz theoretical optimum (1 frame)
- `36ms` = common (frame-alignment adds one frame)
- occasional `55-146ms` = residual WiFi jitter (disappears once signal improves)

**5. Code-side optimizations already built-in** (nothing to configure): host
drains the command queue each frame and applies only the newest, teleop reads
both leader arms concurrently, serial retries removed, `SNDTIMEO` + send
fault-tolerance. If still laggy, check the host log for `Dropping observation`
(client not consuming) or `No command` (commands not arriving).

---

## 12. Project Structure

```
/home/zach/HumanaOpen/
├── pyproject.toml                              # Package config + lerobot entry points (no lerobot dep)
├── lerobot_robot_humanaopen/                   # Main package
│   ├── __init__.py                             # Exports HumanaOpen
│   ├── config_humanaopen.py                    # Config classes (HumanaOpenConfig, LiftAxisConfig, ...)
│   ├── humanaopen.py                           # Main Robot class (follower side)
│   ├── lift_axis.py                            # Lift axis with stall-detection homing
│   ├── leader.py                               # Leader teleoperator (single/bimanual, Section 4.4)
│   ├── humanaopen_host.py                      # ZMQ host (robot side)
│   └── humanaopen_client.py                    # ZMQ client (teleop side)
├── examples/
│   ├── single_machine.py                       # Single machine example (Section 5.1)
│   ├── teleop_keyboard.py                      # Keyboard teleop: i/k/j/l/n/m/u/h/b (Section 5.2)
│   ├── calibrate_follower.py                   # Full follower-side calibration (Section 4.2)
│   ├── calibrate_leader.py                     # Leader arm calibration (Section 4.4)
│   ├── diagnose_teleop.py                      # Teleop direction diagnosis (Section 4.4)
│   ├── test_base_keyboard.py                   # Base-only keyboard test (Section 5.5)
│   ├── test_lift_only.py                       # Lift axis test, homes + 50mm up + 3mm down (Section 9.6)
│   └── check_phase.py                          # Check lift servo velocity unit via Phase BIT2 (Section 9.7)
├── docs/
│   ├── manual_en.md                            # This file
│   └── manual_zh.md                            # 中文手册
└── README.md
```

---

## Quick Start Summary

```bash
# 1. Environment
conda create -n lerobot python=3.12
conda activate lerobot

# 2. LeRobot (local source, 0.4.x)
pip install -e /home/zach/lerobot-so101-bimanual/lerobot

# 3. HumanaOpen
cd /home/zach/HumanaOpen
pip install -e . --no-deps

# 4. Verify (from OUTSIDE the project dir!)
cd /tmp && python -c "import lerobot_robot_humanaopen; print('OK')"

# 5. First connection (2-bus, no cameras)
cd /home/zach/HumanaOpen
python3 -c "
from lerobot_robot_humanaopen import HumanaOpen, HumanaOpenConfig
robot = HumanaOpen(HumanaOpenConfig(port1='/dev/ttyACM0', port2='/dev/ttyACM1', port3=None, cameras={}))
robot.connect(calibrate=False)
robot.disconnect()
print('Bring-up OK')
"

# 6. Lift alone
python3 examples/test_lift_only.py

# 7. Full pipeline
lerobot-record    --robot.type=humanaopen --dataset.repo_id=you/data ...
lerobot-train     --policy.type=act --dataset.repo_id=you/data ...
lerobot-rollout   --policy.path=./outputs/checkpoints/last --robot.type=humanaopen ...
```

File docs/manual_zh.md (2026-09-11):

# HumanaOpen 完整入门教程

本手册面向第一次接触 HumanaOpen 的开发者，从零开始安装环境、接线、测试电机、校准、采集数据、训练模型到部署，全部步骤都经过本项目的实际测试验证。文中所有参数以代码为准（`config_humanaopen.py` 和 `lift_axis.py`），凡标注 ⚠️ 的地方都是实际踩过的坑，请务必留意。

## 概述

HumanaOpen 是一款基于 LeRobot 的开源半人形机器人，拥有：

- **双臂**：2 × 7 自由度 + 夹爪（各 8 个 ST3215 C018 舵机）
- **头部**：2 自由度（ST3215 C018 舵机 × 2）
- **升降**：丝杆驱动（ST3250 舵机 × 1，T8 丝杆，直驱）
- **底盘**：双轮差速驱动（ST3215 C018 舵机 × 2）
- **相机**：头部 × 1 + 左腕 × 1 + 右腕 × 1（默认 640×480 @ 30fps）

完整的遥操-学习闭环与 LeRobot 官方流程一致：`lerobot-record` 采集 → `lerobot-train` 训练 → `lerobot-rollout` 部署。

---

## 一、硬件准备

### 1.1 舵机清单

| 位置 | 舵机 | 数量 | 舵机 ID | 控制模式 |
|---|---|---|---|---|
| 左从臂 J1-J7 + 夹爪 | ST3215 C018 | 8 | 1-8 | POSITION |
| 右从臂 J1-J7 + 夹爪 | ST3215 C018 | 8 | 1-8 | POSITION |
| 头部 Pan / Tilt | ST3215 C018 | 2 | 12, 13 | POSITION |
| 升降丝杆 | ST3250 | 1 | 9 | VELOCITY |
| 左轮 / 右轮 | ST3215 C018 | 2 | 10, 11 | VELOCITY |
| **左主臂** J1-J7 + 夹爪（遥操） | STS3215 C046 | 8 | 1-8 | POSITION |
| **右主臂** J1-J7 + 夹爪（遥操） | STS3215 C046 | 8 | 1-8 | POSITION |

### 1.2 总线拓扑

> **左右臂定义**：以机器人自身为参考系。站在机器人身后、与其面朝同一方向时，位于你左手侧的机械臂为**左臂**（`port1`），右手侧为**右臂**（`port2`）。接线决定物理左右，软件只映射 `left_arm_*` → `port1`、`right_arm_*` → `port2`。

**3 总线模式（默认配置）：**

```
Bus 1 ── 左从臂(1-8) + 头部(12,13) ── POSITION
Bus 2 ── 右从臂(1-8) ── POSITION
Bus 3 ── 升降(9) + 左轮(10) + 右轮(11) ── VELOCITY
```

**2 总线模式（port3=None，本项目实际使用）：**

```
Bus 1 ── 左从臂(1-8) + 头部(12,13) ── POSITION
Bus 2 ── 右从臂(1-8) + 升降(9) + 左轮(10) + 右轮(11) ── 混合模式
```

⚠️ 2 总线模式下 bus2 同时挂着 POSITION 模式的右臂和 VELOCITY 模式的升降/轮子，这是代码支持的（每个电机单独设置 `Operating_Mode`），互不干扰，已实测可用。

`enable_base=False` 时轮子和升降都会自动禁用（`bus3` 不创建，升降也拿不到总线），此时连升降归零都不会执行，适合纯双臂测试。

### 1.3 主臂（遥操端）

主臂使用 STS3215 C046（7.4V），通过另一台电脑（笔记本）连接，与机器人端通过 ZMQ 或直接接同一台机器通信。

### 1.4 供电与菊花链接线（新手必读）

- 从臂 / 升降 / 轮子共 12V 供电，主臂 C046 用 7.4V 独立供电，两者电压不同，切勿混用。
- 同一总线上所有舵机是**菊花链**串联的，中间任何一处断线，会同时失去它之后的所有舵机（详见 FAQ 中 "Missing motor IDs" 的排查）。
- 升降舵机（ID 9）负载大，注意 12V 电源的电流余量，电机多时建议分级供电。

---

## 二、软件安装

### 2.1 创建 conda 环境

推荐用 conda 管理环境，Python 3.12：

```bash
conda create -n lerobot python=3.12
conda activate lerobot
```

⚠️ 之后所有命令都必须在这个 `lerobot` 环境里跑。系统自带 python（比如 conda base 的 3.13）很可能缺 numpy 等依赖，直接 import 就会报错。

### 2.2 安装 lerobot（本地源码）

HumanaOpen 依赖的是**本地源码安装的 lerobot**（版本 0.4.x，本项目位于 `/home/zach/lerobot-so101-bimanual/lerobot`）。注意 PyPI 上的 lerobot 没有 1.0，最新只有 0.6.x，API 有差异。所以 HumanaOpen 的 `pyproject.toml` 刻意**不依赖 PyPI 上的 lerobot**，只声明了 `numpy` 和 `pyzmq`。

```bash
cd /home/zach/lerobot-so101-bimanual/lerobot
pip install -e . --no-deps
```

（如果在自己机器上，把路径换成你的 lerobot 源码路径。`-e` 是 editable 安装，之后改 lerobot 源码实时生效，不用重装。）

### 2.3 安装 HumanaOpen

```bash
cd /home/zach/HumanaOpen
pip install -e . --no-deps
```

⚠️ 一定要带 `--no-deps`。否则 pip 会尝试从 PyPI 拉取 lerobot，和本地源码版冲突。

### 2.4 验证安装

验证必须在**非项目目录**进行，否则当前目录会被 Python 自动加入 path，误以为装好了：

```bash
cd /tmp
python -c "import lerobot_robot_humanaopen; print('OK')"
```

看到 `OK` 才算装好。如果报 `ModuleNotFoundError`，多半是（a）没在 lerobot 环境里，或（b）pip 装到了别的环境。

### 2.5 常见安装失败

| 症状 | 原因 | 解决 |
|---|---|---|
| `ModuleNotFoundError: No module named 'numpy'` | 用了系统 python（非 lerobot 环境） | `conda activate lerobot` 后再跑 |
| 项目目录里 import 成功，换目录失败 | 当前目录被 Python 自动加入 path，不是真装好 | 重新 `pip install -e . --no-deps`，在 `/tmp` 下验证 |
| 运行时 lerobot API 报错 | 装到了 PyPI lerobot | `pip show lerobot` 查版本，重装本地源码版 |

---

## 三、舵机 ID 配置（首次使用）

只有新舵机需要配置 ID。**每个舵机逐个连接到 Waveshare 板进行配置：**

### 3.1 接线

- 将 Waveshare 板通过 USB 连接到电脑
- **每次只连接一个舵机**到 Waveshare 板
- 给舵机供电（12V 电源）

### 3.2 运行配置

```python
from lerobot_robot_humanaopen import HumanaOpen, HumanaOpenConfig

config = HumanaOpenConfig(port1="/dev/ttyACM0", port2="/dev/ttyACM1")
robot = HumanaOpen(config)

# 这会逐个提示你连接舵机并设置 ID
robot.setup_motors()
```

按提示操作，每次只连接提示的舵机，然后按 Enter。

⚠️ 提示顺序是**倒着**来的（从大 ID 到小 ID）。新舵机出厂 ID 都是 1，如果先把 1 号设好再插别的舵机，会和新插舵机的出厂 ID 冲突。

### 3.3 主臂舵机 ID 设置

主臂的 C046 舵机 ID 同样设置为 1-8（左右臂各一套），通过另一个 Waveshare 板连接。可以用相同的 `setup_motors()` 方法，但修改端口指向主臂的 Waveshare 板。

### 3.4 Missing motor IDs 排查

`connect()` 报 `Missing motor IDs: ...` 说明总线上有舵机没被找到。按顺序检查：

1. **菊花链断线**：同一总线是串联的，比如 6→7 之间断线，会导致 7 及之后全部失联，报错里会同时缺 7、8。用 `broadcast_ping` 扫描（见 5.3）从断点往前查线。
2. **舵机 ID 未烧录**：新舵机出厂 ID 都是 1，重复 ID 或 ID 与预期不符也会失联。用 `setup_motors()` 重新烧录。
3. **供电不足**：舵机太多时 12V 电源电流不够，末端舵机会随机失联。

---

## 四、校准

### 4.1 完整校准（从动侧）

lerobot 的完整管线（record / train / rollout）**必须先校准**。校准包含：

- **关节舵机**：半圈归中 + 全行程录制
- **车轮**：设置为连续旋转全范围
- **升降**：堵转检测自动归零

推荐用校准脚本（带完整步骤提示和校准后验证）：

```bash
python3 examples/calibrate_follower.py
```

或手动运行：

```bash
python3 -c "
from lerobot_robot_humanaopen import HumanaOpen, HumanaOpenConfig
robot = HumanaOpen(HumanaOpenConfig(id='follower'))
robot.connect(calibrate=True)
"
```

按提示操作：

1. 有校准文件时提示输入回车（自动恢复）或输入 `c` 手动校准
2. 如果选择手动校准：
   - 将左臂和头部关节移到**零位姿态**（手臂自然下垂、夹爪闭合）→ 按 Enter
   - 依次移动每个关节走完全范围 → 按 Enter 停止录制
   - 右臂做同样操作
   - 夹爪有专门的闭合/张开两步标定（0=闭合，100=张开）
3. 升降会自动进行堵转归零

⚠️ 校准过程中手臂是**掉扭矩**的，需要手动移动关节。移动时要温柔，不要硬掰。

**零位约定（重要）**：从臂和主臂统一用"**手臂自然下垂 + 夹爪闭合**"作为零位。这样遥操时主臂下垂 → 从臂也下垂（姿态一一对应），录数据时 action/obs 的归一化空间物理一致。走行程时尽量**绕零位对称**地移动（两端都走到），让量程中点 ≈ 零位。

### 4.2 标定文件存储位置

**从动侧（follower）**：`~/.cache/huggingface/lerobot/calibration/robots/humanaopen/{id}.json`

```
.../humanaopen/follower.json   ← 从动侧校准 (id="follower")
```

校准过的机器人下次 `connect()` 会自动加载，并提示按 Enter 恢复校准或输入 `c` 重新校准。

**主动侧（leader）**：存储在 teleoperators 目录（见 4.3），与从动侧完全分开。

### 4.3 主臂（leader）校准

主臂是 open-arms-mini 结构（STS3215 C046，7.4V），左右各 8 舵机（ID 1-8），关节命名与从臂一致。用校准脚本：

```bash
python3 examples/calibrate_leader.py
```

每臂交互流程（默认 `calibration_mode="full"`，录真实行程）：

1. **手臂自然下垂 + 夹爪闭合** → 回车（设为零点）
2. **逐个关节走满行程**（两端之间）→ 回车（录真实 min/max，与从臂归一化空间一致）
3. **夹爪闭合位置** → 回车
4. **夹爪张开位置** → 回车
5. 保存校准

**为什么主臂也要录真实行程？** 录数据训练时，`action` 来自主臂、`observation` 来自从臂。若主臂用全量程而从臂录行程，同一物理姿态下两套归一化空间含义不同（主臂 50 ≠ 从臂 50），模型学到错误映射，部署时动作不到位。主臂录真实行程后，两套空间物理对齐，**遥操和录数据共用同一份校准，无需重校**。

> 若只需纯实时遥操（人实时补偿），可设 `calibration_mode="quick"`（关节全量程 [0,4095]，官方 openarm_mini 简化方式）。但录数据训练前必须改回 `"full"` 并重校。

校准文件（与从臂分开，互不覆盖）：

```
~/.cache/huggingface/lerobot/calibration/teleoperators/humanaopen_leader/leader_left.json
~/.cache/huggingface/lerobot/calibration/teleoperators/humanaopen_leader/leader_right.json
```

主臂实现（`lerobot_robot_humanaopen/leader.py`）：

- `humanaopen_leader`：单臂 teleoperator（`calibration_mode`: `full`/`quick`）
- `bi_humanaopen_leader`：双臂 teleoperator（输出 `left_arm_*`/`right_arm_*` 前缀）

遥操时 `leader.get_action()` 的动作键与从臂 `follower.send_action()` 完全对齐，可零转换对接。

**方向翻转 / 腕部重映射（可配置）**：

默认 `flip_joints` / `joint_remap` 采用官方 openarm_mini 的值（针对官方主从臂配对）。**如果你的主从臂装配与官方不同，部分关节方向会反、腕部映射会错**——这是硬件相关，不是 bug。用诊断脚本逐关节实测：

```bash
python3 examples/diagnose_teleop.py
```

根据诊断结果配置（`BiHumanaOpenLeaderConfig` / `HumanaOpenLeaderConfig`）：

```python
config = BiHumanaOpenLeaderConfig(
    left_arm_port="/dev/ttyACM2",
    right_arm_port="/dev/ttyACM3",
    # 方向反的关节加入对应侧列表; 不需要腕部交换则置空 dict
    flip_joints={"left": ["shoulder_pan", ...], "right": [...]},
    joint_remap={},  # 不需要腕部 flex↔yaw 交换
)
```

夹爪输出直接是 [0,100]（0=闭，100=开），与从臂 `RANGE_0_100` 同构，无额外缩放。

⚠️ 主臂 7.4V 供电（与从臂 12V 分开），校准中扭矩释放可手动摆动。

### 4.4 未校准时的正常报错：no calibration registered

没有校准文件就 `connect(calibrate=False)`，再用 `robot.get_observation()` 读关节位置时，会看到类似 "no calibration registered" 的报错。

⚠️ **这是正常的**。未校准时电机读数无法归一化到 -100..100（或角度），`get_observation()` 自然读不了。升降测试应绕过它：直接用 `robot.lift_axis.get_height_mm()` 读高度，完全不需要校准。

### 4.5 摄像头查找

摄像头不在默认位置（`/dev/video0`、`/dev/video2`、`/dev/video4`）时，用官方命令找设备号：

```bash
lerobot-find-cameras opencv
```

它会列出检测到的摄像头及对应的设备号/索引，把结果填进 `HumanaOpenConfig` 的 `cameras` 字段（或 record 命令行的 `--robot.cameras`）。

---

## 五、运行模式

### 5.1 单机模式（全插一台机器）

所有 Waveshare 板和相机都插在同一台电脑（笔记本或 Jetson）：

```python
from lerobot_robot_humanaopen import HumanaOpen, HumanaOpenConfig

config = HumanaOpenConfig(
    port1="/dev/ttyACM0",   # 左臂+头
    port2="/dev/ttyACM1",   # 右臂
    port3="/dev/ttyACM2",   # 升降+车轮（3 总线模式）
)
robot = HumanaOpen(config)
robot.connect()

# 采集一帧观察
obs = robot.get_observation()
print(obs.keys())

# 发送动作（保持静止）
action = {k: obs[k] for k in obs if k.endswith(".pos")}
action["x.vel"] = 0.0
action["theta.vel"] = 0.0
action["lift_axis.height_mm"] = obs.get("lift_axis.height_mm", 0)
robot.send_action(action)

robot.disconnect()
```

⚠️ 用 2 总线模式就把 `port3=None`；还没装相机就加 `cameras={}` 跳过，电机照样能测。参考 `examples/single_machine.py`。

### 5.2 连接测试与排障（快速自检）

**推荐流程**：先用 `cameras={}` 把电机这半边测通，再逐步加相机：

```python
from lerobot_robot_humanaopen import HumanaOpen, HumanaOpenConfig

config = HumanaOpenConfig(
    port1="/dev/ttyACM0",
    port2="/dev/ttyACM1",
    port3=None,          # 2 总线模式（本项目实际使用）
    cameras={},          # 跳过摄像头
)
robot = HumanaOpen(config)
robot.connect(calibrate=False)   # 不校准也能连接、能测升降
print("connected:", robot.is_connected)
robot.disconnect()
```

⚠️ 注意 `connect(calibrate=False)` 仍然会**自动执行升降归零**（向下找底堵转即停），这是设计行为。

### 5.3 总线电机扫描

某条总线上不确定哪些舵机在线时，用 `broadcast_ping` 扫描。**必须先 `bus.connect()`**，否则会报 `'NoneType'` 对象没有 `flush` 的错误：

```python
from lerobot.motors.feetech import FeetechMotorsBus

bus = FeetechMotorsBus(port="/dev/ttyACM0", motors={})
bus.connect()
print(bus.broadcast_ping())   # 返回 {舵机ID: 型号编号}
bus.disconnect()
```

输出形如 `{1: 45, 2: 45, ..., 12: 45, 13: 45}`，一眼就能看出哪些 ID 在线、哪些失联，是排查菊花链断点最快的办法。

### 5.4 端口漂移确认

⚠️ 断电重插后，`/dev/ttyACM0` 和 `/dev/ttyACM1` **可能互换**。判断实际端口用序列号：

```bash
ls -l /dev/serial/by-id/
```

`by-id` 下的符号链接按 USB 序列号命名，拔插后稳定不变。如果每块 Waveshare 板序列号不同，可以用 udev 规则绑定固定名字（见 FAQ）。

### 5.5 键盘控制与权限

**键盘库选择（Linux 必读）**

两个键盘监听库，权限要求不同：

- **`pynput`（推荐）**：桌面 X11 环境下**无需 root**，直接运行。需已设置 `DISPLAY`（桌面终端默认有）。
- **`keyboard`**：在 Linux 上**强制要求 root**（`ensure_root()` 硬检查），加 `input` 组也没用。要么 sudo 运行，要么换 pynput。

```bash
# 安装 pynput
pip install pynput
```

**底盘键盘手动测试**

只有底盘、不碰手臂和升降的键盘控制脚本（无需校准）：

```bash
python3 examples/test_base_keyboard.py
```

键位：`i/k` 前进/后退，`j/l` 左转/右转，`n/m` 加减速（3 档：0.05/0.10/0.20 m/s），`b` 退出。按住移动，松开即停。

> ⚠️ 建议把机器人架起（轮子离地）再测试底盘方向；落地测试要确保周围无障碍物。

> 若使用 `keyboard` 库且需 sudo：`sudo /home/zach/miniconda3/envs/lerobot/bin/python examples/test_base_keyboard.py`（必须用 conda 环境 python 完整路径，否则 sudo 会用系统 python 找不到包）。

**底盘方向修正（左右轮装反）**

如果按 `i`（前进）实际变成原地转向、`j`（左转）变成前进，说明**某一侧轮子物理装反了**（正转=后退）。差速指令会让两轮相向而转，看起来就是前进/转向互换了。

修复：在配置里把装反的那一侧设成 `-1`：

```python
config = HumanaOpenConfig(
    ...
    wheel_dir_signs={
        "base_left_wheel": -1,   # 左轮装反 → 取反
        "base_right_wheel": 1,   # 右轮正常
    },
)
```

`+1` = 正 raw 速度驱动轮子向前；`-1` = 该轮装反。指令路径（`_body_to_wheel_raw`）和反馈路径（`_wheel_raw_to_body`）都会应用该符号，保持体坐标系一致。判断哪个轮反了：按 `i` 若往左转，则左轮反；往右转则右轮反。

**跳过升降归零**

`connect()` 默认会自动执行升降归零。测试底盘或其他子系统、且升降已在已知位置时，可跳过：

```python
config = HumanaOpenConfig(
    port1="/dev/ttyACM0",
    port2="/dev/ttyACM1",
    port3=None,
    cameras={},
    home_lift_on_connect=False,   # 跳过自动升降归零
)
```

升降只会被注册和配置（不会运动）。

### 5.6 双机 ZMQ 模式（笔记本遥操 + Jetson/树莓派机器端）

**机器端（Jetson/树莓派）：**

```bash
python3 -c "
from lerobot_robot_humanaopen import HumanaOpenConfig
from lerobot_robot_humanaopen.humanaopen_host import HumanaOpenHost

host = HumanaOpenHost(HumanaOpenConfig())
host.run()
"
```

默认端口：obs 5556 / cmd 5555。

**遥操端（笔记本）：**

```python
from lerobot_robot_humanaopen.humanaopen_client import HumanaOpenClient
from lerobot_robot_humanaopen import HumanaOpenClientConfig

client = HumanaOpenClient(
    HumanaOpenClientConfig(remote_ip="192.168.1.100")  # Jetson/树莓派 IP
)
client.connect()

obs = client.get_observation()
# 接入主臂遥操或键盘控制
# ...

client.send_action(action)
client.disconnect()
```

---

## 六、数据采集

### 6.1 使用 lerobot-record（推荐）

```bash
lerobot-record \
    --robot.type=humanaopen \
    --robot.port1=/dev/ttyACM0 \
    --robot.port2=/dev/ttyACM1 \
    --robot.port3=/dev/ttyACM2 \
    --robot.cameras='{"head": {"type": "opencv", "index_or_path": 0, "fps": 30, "width": 640, "height": 480}, "left_wrist": {"type": "opencv", "index_or_path": 2, "fps": 30, "width": 640, "height": 480}, "right_wrist": {"type": "opencv", "index_or_path": 4, "fps": 30, "width": 640, "height": 480}}' \
    --teleop.type=openarm_mini \
    --teleop.port=/dev/ttyACM_leader \
    --dataset.repo_id=你的名字/my_humanaopen_data \
    --dataset.num_episodes=10 \
    --dataset.single_task="描述你的任务"
```

要点：

- 摄像头设备号先用 `lerobot-find-cameras opencv` 确认，再填 `index_or_path`。
- 摄像头名（`head`、`left_wrist`、`right_wrist`）**必须**与训练、部署时保持一致，分辨率也一样（见 8.1 的警告）。
- 纯双臂采集（还没装轮子/升降）时加 `--robot.enable_base=false`。
- 在 Jetson 上 `index_or_path` 可能是 `/dev/video*` 路径而不是整数，按 `lerobot-find-cameras opencv` 的输出填。

### 6.2 双机 ZMQ 模式数据采集

**机器端：**

```bash
python3 -c "
from lerobot_robot_humanaopen import HumanaOpenConfig
from lerobot_robot_humanaopen.humanaopen_host import HumanaOpenHost
HumanaOpenHost(HumanaOpenConfig()).run()
"
```

**遥操端：**

```bash
# 遥操端运行记录脚本，从 ZMQ 获取 obs，发送 action
# 数据集保存在遥操端（或可以配置保存路径）
```

---

## 七、模型训练

数据采集完成后，直接在任意机器上训练：

```bash
lerobot-train \
    --policy=act \
    --dataset.repo_id=你的名字/my_humanaopen_data \
    --output_dir=./outputs
```

训练参数可在命令行覆盖：

```bash
lerobot-train --policy=act --dataset.repo_id=... --training.batch_size=32 --training.epochs=100
```

支持的策略类型：`act`、`diffusion`、`smolvla`、`pi0`、`pi05`、`groot` 等。**同一份数据无需重新采集**，只需改 `--policy.type` 即可切换策略对比效果。

---

## 八、模型部署（推理）

### 8.1 单机推理

```bash
lerobot-rollout \
    --policy.path=./outputs/checkpoints/last \
    --robot.type=humanaopen \
    --robot.port1=/dev/ttyACM0 \
    --robot.port2=/dev/ttyACM1 \
    --robot.port3=/dev/ttyACM2
```

⚠️ **摄像头名和分辨率必须与采集时完全一致**（`head` / `left_wrist` / `right_wrist`，同 640×480）。rollout 时改了摄像头名或分辨率，策略的特征维度对不上，会直接报错。

### 8.2 双机 ZMQ 推理

**机器端运行 ZMQ host，遥操端运行 rollout：**

```bash
# 机器端
python3 -c "
from lerobot_robot_humanaopen import HumanaOpenConfig
from lerobot_robot_humanaopen.humanaopen_host import HumanaOpenHost
HumanaOpenHost(HumanaOpenConfig()).run()
"
```

遥操端目前需要手动加载策略并通过 ZMQ client 发送动作。

---

## 九、升降操作（重点）

升降使用 ST3250 舵机 + T8 丝杆（导程 8mm，行程 300mm，直驱无皮带）。**这是本项目踩坑最多的地方，请完整读这一节。**

### 9.1 归零流程

`connect()` 时升降会自动归零，流程是：

1. 向下走（`Goal_Velocity = -home_down_speed`）
2. **堵转检测**（双保险）：`Present_Current` 电流超过阈值（`home_stall_current_ma=200`），或编码器位置连续两次读数不动（位置冻结），都判定已到底
3. **回退 5°**（`home_backoff_deg=5`，切到 POSITION 模式微抬一下，释放丝杆应力）
4. 记录零点
5. 恢复：写 `Goal_Velocity=0` → 切回 VELOCITY 模式 → 重新上扭矩 → 零点微调

归零后系统自动恢复 VELOCITY 模式 + 扭矩，**可以直接控制**，无需额外操作。

### 9.2 速度单位（关键！）

ST3250 的速度单位由**相位寄存器（地址 18）的 BIT2** 决定：

| BIT2 | 速度单位 | 达到 7.5mm/s 所需 v_max |
|---|---|---|
| 0 | 0.732 RPM/raw | ≈ 77 |
| 1 | 0.0146 RPM/raw | ≈ 3853 |

**本机实测 BIT2 = 1**（0.0146 RPM/raw），所以 `v_max=3853` 对应约 7.5mm/s，300mm 行程约 40 秒。

⚠️ 速度单位用错是"升降不动"和"升降猛冲"两大症状的根源：

- 以为单位是 0.732，把 `v_max` 设成 80（0.732 单位下 ≈ 58 RPM）：实际 80 × 0.0146 ≈ 1.2 RPM，**几乎不动**
- 以为单位是 0.732，把 `v_max` 设成 4200（旧文档值）：实际 4200 × 0.0146 ≈ 61 RPM，位置环震荡**过冲**

改 `v_max` 之前，先用 `check_phase.py` 确认自己舵机的 BIT2：

```bash
cd /home/zach/HumanaOpen
python3 examples/check_phase.py
```

输出会直接告诉你 BIT2 是 0 还是 1，以及对应的 v_max 建议值。**不要照抄别人的 v_max，先跑这个脚本。**

### 9.3 高度控制（推荐）

```python
# 读取当前高度
height = obs["lift_axis.height_mm"]

# 设置目标高度
action["lift_axis.height_mm"] = 200.0  # 单位 mm
```

内部是 P 控制器：`v_cmd = kp_vel × (目标 - 当前)`，夹在 `±v_max` 之间，再经过安全限位。

### 9.4 直接速度控制

```python
action["lift_axis.vel"] = 500  # 原始速度值，正=上升，负=下降
```

同样会被 `±v_max` 夹住并经过安全限位。

### 9.5 安全保护

- **下限硬保护**：`descent_floor_mm=3`。当前高度 ≤ 3mm 时，任何下行指令都会被压成 0。⚠️ 测试目标高度不能低于 3mm。
- **软限位**：`soft_min_mm=0`、`soft_max_mm=280`，越界方向的速度被钳 0。280mm 是为 300mm 丝杆行程预留 20mm 机械安全余量，避免惯性过冲撞顶。
- **堵转检测**：归零时自动检测（电流 + 位置冻结双保险）。

### 9.6 升降轴测试

验证升降硬件和软件是否正常，无需手臂/摄像头：

```bash
conda activate lerobot
cd /home/zach/HumanaOpen
python3 examples/test_lift_only.py
```

流程：连接 → 自动向下归零（堵转即停）→ 升 50mm → 降回 3mm。

- **安全**：脚本含 Ctrl+C 紧急停止（写 `Goal_Velocity=0` + `Torque_Enable=0`）
- **前置**：升降舵机（ID 9）需接在 bus2（`/dev/ttyACM1`）上，12V 供电
- **无需**：手臂、轮子、摄像头、校准
- 该脚本绕过了 `HumanaOpen` 类，直接创建只含升降电机的总线，**不碰右臂/轮子/手臂**，排查时最干净

### 9.7 Ctrl+C 紧急停止（重要）

⚠️ **舵机是硬件，不是 Python 对象。** 收到速度指令后会持续转，`Ctrl+C` 退出 Python 进程**不会自动让它停**。必须显式给总线写：

```python
bus.write("Goal_Velocity", "lift_axis", 0)     # 停
bus.write("Torque_Enable", "lift_axis", 0)     # 掉扭矩（可选，让它完全放松）
```

正确写法是把业务逻辑包在 `try/finally`（或 `except KeyboardInterrupt`）里，参考 `test_lift_only.py`：

```python
try:
    lift.home()
    # ... 测试逻辑 ...
except KeyboardInterrupt:
    print("紧急停止...")
    bus.write("Goal_Velocity", "lift_axis", 0)
    bus.write("Torque_Enable", "lift_axis", 0)
finally:
    bus.disconnect()
```

`lift_axis.py` 内部的 `home()` 也做了同样的处理：Ctrl+C 时先停再抛，不会让丝杆继续往下钻。

---

## 十、配置参数说明

### 10.1 HumanaOpenConfig

| 参数 | 默认值 | 说明 |
|---|---|---|
| `port1` | `/dev/ttyACM0` | 左臂+头部总线端口 |
| `port2` | `/dev/ttyACM1` | 右臂总线端口 |
| `port3` | `/dev/ttyACM2` | 升降+车轮总线端口；设 `None` 启用 2 总线模式 |
| `enable_base` | `True` | 设为 `False` 禁用底盘（轮子）和升降，纯双臂测试 |
| `home_lift_on_connect` | `True` | 设为 `False` 跳过 connect 时的自动升降归零（测试其他子系统时用） |
| `disable_torque_on_disconnect` | `True` | 断开时是否释放扭矩 |
| `max_relative_target` | `None` | 单步位置变化上限（度或 %）；`None` 不限制 |
| `use_degrees` | `False` | `False` 用 -100..100 归一化范围，`True` 用角度 |
| `cameras` | 见 `default_cameras()` | 相机配置（`head` / `left_wrist` / `right_wrist`），可传 `{}` 跳过 |
| `wheel_radius` | 0.0635 m | 车轮半径（127mm 轮径） |
| `wheelbase` | 0.30 m | 轮距 |
| `max_wheel_raw` | 3000 | 最大车轮速度原始值 |
| `wheel_dir_signs` | 两轮 `+1` | 轮子方向符号；某一侧装反时设 `-1`（见 5.5） |
| `teleop_keys` | 见 10.3 | 键盘遥操键位映射 |

### 10.2 LiftAxisConfig

| 参数 | 默认值 | 说明 |
|---|---|---|
| `enabled` | `True` | 设为 `False` 完全禁用升降 |
| `motor_id` | 9 | 升降舵机 ID |
| `motor_model` | `"sts3250"` | 升降舵机型号（ST3250） |
| `lead_mm_per_rev` | 8.0 | 丝杆导程 (mm/圈) |
| `belt_ratio` | 1.0 | 丝杆每电机转数比；`1.0` = 直驱无皮带 |
| `soft_min_mm` | 0.0 | 软下限 (mm) |
| `soft_max_mm` | 280.0 | 软上限 (mm)，300mm 丝杆行程留 20mm 安全余量 |
| `descent_floor_mm` | 3.0 | 下降硬保护高度 (mm)，低于它拒绝下行 |
| `home_down_speed` | 1500 | 归零下行速度（原始速度值） |
| `home_stall_current_ma` | 200 | 堵转电流阈值 (mA) |
| `home_backoff_deg` | 5.0 | 堵转后回退角度 (°) |
| `kp_vel` | 500.0 | 位置→速度 P 控制器增益 |
| `v_max` | **3853** | 最大速度指令（BIT2=1 时 ≈ 7.5mm/s） |
| `on_target_mm` | 1.0 | 到达判定死区 (mm) |
| `dir_sign` | 1 | 正速度方向；`+1` 表示正速度=上升 |

⚠️ `v_max` 以本机实测的 BIT2=1 为准（3853）。如果你的舵机 BIT2=0，需要改成 ≈77（先跑 `check_phase.py` 确认）。

### 10.3 键盘遥操键位（teleop_keys）

| 键 | 功能 |
|----|---|
| `i` / `k` | 前进 / 后退 |
| `j` / `l` | 左转 / 右转 |
| `n` / `m` | 加速档 / 减速档 |
| `u` / `h` | 升降升 / 升降降 |
| `b` | 退出 |

⚠️ **注意：升降下降键是 `h`，不是 `d`！** 这是本项目的自定义修改，很多初学者按 `d` 没反应。源码见 `config_humanaopen.py` 的 `teleop_keys`。

---

## 十一、常见问题

### Q: 报错 "Missing motor IDs" 怎么办？

A: 总线上有舵机没被找到。按顺序排查：

1. **菊花链断线**：总线是串联的，6→7 之间断线会导致 7 及之后全部失联。用 `broadcast_ping` 扫描（见 5.3），看哪些 ID 在线。
2. **舵机 ID 未烧录**：新舵机出厂 ID=1，重复 ID 或未按预期设置都会导致失联。用 `setup_motors()` 逐个重烧。
3. **供电不足**：电机太多时 12V 电源电流不够，末端舵机会失联。单独给升降/轮子供电试试。

### Q: 设备端口 (/dev/ttyACM0) 每次重启后变化？

A: 断电重插后 `ttyACM0` / `ttyACM1` 可能互换。先看实际端口：

```bash
ls -l /dev/serial/by-id/
```

`by-id` 按序列号命名，拔插不变。再用 udev 规则绑定固定名字：

```bash
# /etc/udev/rules.d/99-waveshare.rules
SUBSYSTEM=="tty", ATTRS{idVendor}=="1a86", ATTRS{serial}=="A1", SYMLINK+="tty_left_arm"
SUBSYSTEM=="tty", ATTRS{idVendor}=="1a86", ATTRS{serial}=="A2", SYMLINK+="tty_right_arm"
SUBSYSTEM=="tty", ATTRS{idVendor}=="1a86", ATTRS{serial}=="A3", SYMLINK+="tty_base"
```

然后在 Config 中使用 `/dev/tty_left_arm` 等固定路径。

### Q: 报错 "no calibration registered"？

A: 正常现象。未校准时 `get_observation()` 无法归一化关节读数。要么先校准（`connect(calibrate=True)`），要么绕过它：升降测试直接用 `robot.lift_axis.get_height_mm()`。

### Q: 升降完全不动？

A: 按顺序检查：

1. **模式**：升降舵机必须是 VELOCITY 模式。归零后代码会自动恢复，但如果手动改过 `Operating_Mode`，需重新 `connect()` 或 `lift_axis.configure()`。
2. **扭矩**：`Torque_Enable` 是否为 1。舵机掉扭矩后用手能自由转动。
3. **速度单位**：见 9.2。代码现在**自动把 Phase BIT2 切到 0**（50 step/s/raw），`v_max=110` 是正确值。如果发现升降"蠕动"（肉眼几乎不动），**先跑 `check_phase.py` 看 BIT2 是不是 1**——通常是换了新舵机（出厂默认 BIT2=1），正常 `connect()` 会自动修正，但手动确认最稳。
4. **下限保护**：高度已经 ≤ `descent_floor_mm=3` 时，下行指令会被压成 0，属于正常保护。
5. 检查接线/供电，用 `broadcast_ping` 看 ID 9 是否在线。

### Q: 升降猛冲 / 过冲？

A: 几乎都是**速度单位失配**。代码按 BIT2=0（50 step/s/raw）标定，`v_max=110` ≈ 8.7mm/s。如果之前手动改过 `v_max` 为按 BIT2=1 算的值（如 3853），会严重超预期。先跑 `check_phase.py` 确认 BIT2，再改回 `v_max=110`。如果 BIT2 正确仍过冲，可降低 `kp_vel`。

### Q: Ctrl+C 后升降还在转？

A: 舵机是硬件，Python 退出不会自动停。必须显式写 `Goal_Velocity=0` + `Torque_Enable=0`。业务逻辑要包在 `try/finally` 里，参考 `test_lift_only.py` 和 9.7 节。

### Q: 主臂和从臂的电压不同怎么办？

A: 主臂 C046（7.4V）和从臂 C018（12V）分别用不同的电源供电。ZMQ 模式两台机器各自供电；单机模式用两个电源分别给 Waveshare 板供电。

### Q: 相机找不到？

A: 先跑 `lerobot-find-cameras opencv` 确认设备号，再填进 `cameras` 配置。还没装相机时用 `cameras={}` 跳过，不影响电机测试。

### Q: 升降速度太慢？

A: 代码按 BIT2=0 标定，`v_max=110` ≈ 8.7mm/s，200mm 约 23 秒。如果实测远慢于此（蠕动级别），**几乎一定是 Phase BIT2 掉回 1**——换新舵机后出厂默认就是 BIT2=1。正常 `connect()` 会自动切回 BIT2=0，但如果不确定，手动确认：

```bash
python3 examples/check_phase.py          # 看 BIT2
python3 examples/switch_phase_bit2.py    # 切到 BIT2=0（若为 1）
```

**换了升降舵机后（重要）**：新舵机出厂 Phase BIT2=1，且旧 `~/.cache/humanaopen/lift_zero.json` 是旧电机数据，两者都要处理：

```bash
rm ~/.cache/humanaopen/lift_zero.json          # 删旧零位
python3 examples/check_phase.py                # 确认速度单位
python3 examples/switch_phase_bit2.py          # 切 BIT2=0
# 之后正常启动即可；代码会自动校验（Model_Number + 三角一致性）
# 检测到电机更换 → 自动 re-home，无需手动删文件
```

### Q: 用 2 总线还是 3 总线？

A: 本项目实际用的是 **2 总线**（`port3=None`）：升降和轮子并入 bus2，已实测可用。3 总线模式（默认）是完整形态，Waveshare 板够多、想让升降/轮子独占一条总线时用默认即可。

### Q: 双机（ZMQ）遥操延迟大 / 从臂跟不上？

A: 延迟 = 网络链路 + 控制循环 + 代码开销三层叠加。从下到上排查：

**1. 物理层（先查，最常见）**——遥操端或机器人端的 WiFi 信号差导致延迟尖峰：
```bash
iw dev <接口名> link | grep signal     # 目标 > -60dBm；-70~-80 会有 100ms+ 尖峰
# -79dBm 实测会从"偶发 200ms 尖峰"恶化到"19 秒卡死"（TCP 重传风暴）
```
- **信号差的修复**：插好/更换 M.2 天线（Jetson Orin 默认小陶瓷天线增益低，外置棒状天线可改善 20dB+）、靠近路由器、换 5GHz 频段。
- 实测：-79dBm 时 RTT 波动到 19 秒；插天线后 -59dBm，RTT 稳定 18-36ms。
- 信号正常后仍偶发尖峰 → 关 WiFi 省电 + 停 NetworkManager 扫频：
```bash
sudo iw dev <接口名> set power_save off
sudo killall -STOP NetworkManager        # Nexus/Tegra 板周期扫频会造成 ~3 秒级尖峰
```

**2. 代理不影响 ZMQ（可跳过）**——ZMQ 是裸 TCP，**不读** `http_proxy`/`all_proxy` 环境变量（libzmq 源码零引用，仅显式 `ZMQ_SOCKS_PROXY` 生效）。系统代理模式不会劫持 5555/5556；只有 Clash **TUN 模式**（虚拟网卡）会劫持。确认无 TUN：
```bash
ip link show | grep -iE 'utun|tun|meta|mihomo'   # 无输出 = 代理不影响遥操
```

**3. 控制循环频率**——默认 30Hz 时两端各一整帧（33ms）的等待，2 帧管道延迟约 66ms。已支持 60Hz：
```bash
# host 端默认已是 60Hz（max_loop_freq_hz=60）
# 遥操端加 --fps=60 与 host 对齐：
python3 examples/teleop_leader_to_follower.py --remote_ip=192.168.1.9 --fps=60
```
- 60Hz 后理论延迟减半（→ ~33ms），host 串口最差帧 8ms、遥操端 1.7ms，余量充足。
- 若 host 日志出现 "worst frame > 17ms"（60Hz 预算）说明串口繁忙，退回 30Hz 或检查总线。

**4. 查看真实延迟**——状态行显示 `rtt:` 是**无时钟偏差**的往返延迟（client 命令带 perf 时间戳 → host 回显 → client 用自己的单调时钟算），比墙钟差可靠。正常值：
- `18ms` = 60Hz 理论最优（1 帧）
- `36ms` = 常见（帧对齐多等 1 帧）
- 偶发 `55-146ms` = WiFi jitter 残留（信号改善后消失）

**5. 代码层已内置的优化**（无需手配）：host 每帧 drain 命令队列只执行最新、遥操端双臂并行读取、去串口重试、`SNDTIMEO` + 发送容错。若仍卡顿，检查 host 日志有无 `Dropping observation`（client 未消费）或 `No command`（命令未到达）。

---

## 十二、项目结构

```
/home/zach/HumanaOpen/
├── pyproject.toml                              # 包配置 + lerobot 入口点（不依赖 PyPI lerobot）
├── lerobot_robot_humanaopen/                   # 主包
│   ├── __init__.py                             # 导出 HumanaOpen
 │   ├── config_humanaopen.py                    # 配置类（HumanaOpenConfig / LiftAxisConfig / ZMQ 配置）
 │   ├── humanaopen.py                           # 主 Robot 类（从动侧）
 │   ├── lift_axis.py                            # 升降轴控制（堵转归零 + P 控制器）
 │   ├── leader.py                               # 主臂 teleoperator（单臂/双臂，见 4.4）
 │   ├── humanaopen_host.py                      # ZMQ 双机模式 Host
 │   └── humanaopen_client.py                    # ZMQ 双机模式 Client
 ├── examples/
 │   ├── single_machine.py                       # 单机使用示例
 │   ├── teleop_keyboard.py                      # 键盘遥操示例
 │   ├── calibrate_follower.py                   # 从动侧全身校准（见 4.1）
 │   ├── calibrate_leader.py                     # 主臂校准（见 4.4）
 │   ├── diagnose_teleop.py                      # 遥操方向诊断（见 4.4）
 │   ├── test_base_keyboard.py                   # 底盘键盘手动测试（见 5.5）
 │   ├── test_lift_only.py                       # 升降轴测试（见 9.6）
 │   └── check_phase.py                          # 检查舵机速度单位（见 9.2）
├── docs/
│   ├── manual_zh.md                            # 本文件
│   └── manual_en.md                            # English manual
└── README.md
```

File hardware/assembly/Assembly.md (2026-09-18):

# HumanaOpen Assembly Guide

Step-by-step instructions to assemble a HumanaOpen robot. Chinese version:
[Assembly_zh.md](Assembly_zh.md).

# 1. Chassis Assembly

## (1) Mount the servo to the bracket

Fix the ST3215 C018 servo into the servo bracket (base) using the screws that
come with the servo.

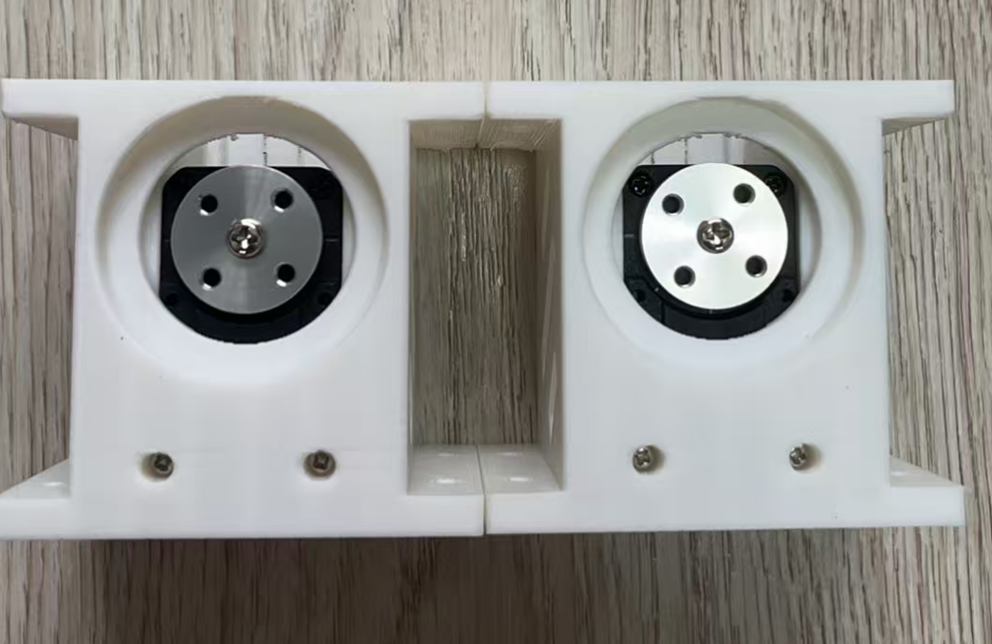
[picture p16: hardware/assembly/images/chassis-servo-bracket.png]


Note: clear out the supporting structure inside the bracket.

## (2) Fix the servo bracket to the chassis

Use 8 pcs M3*22 screws to fix the ST3215 C018 servo base to the chassis.

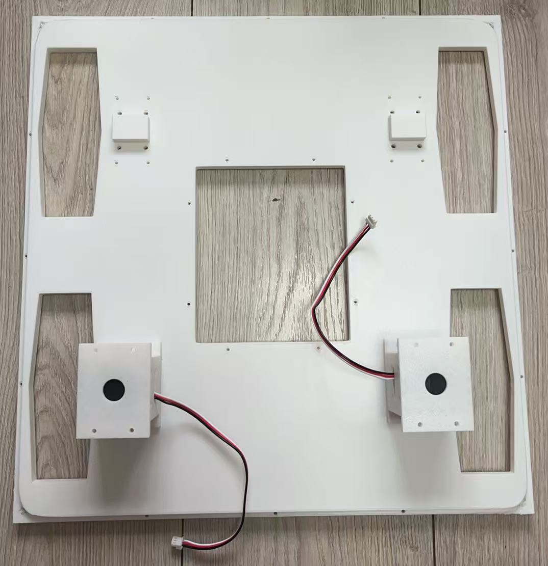
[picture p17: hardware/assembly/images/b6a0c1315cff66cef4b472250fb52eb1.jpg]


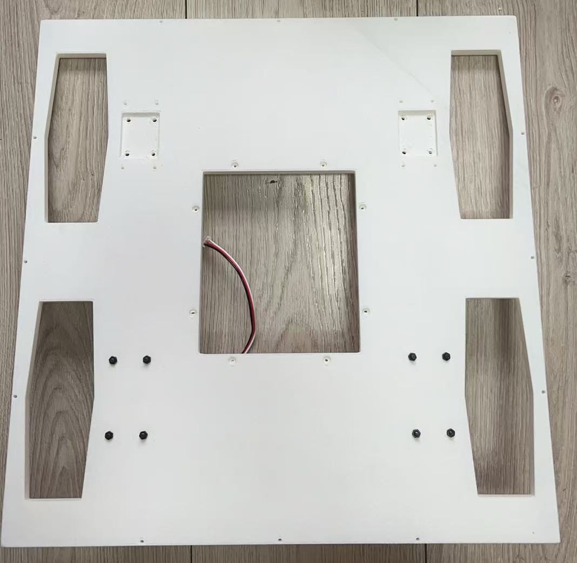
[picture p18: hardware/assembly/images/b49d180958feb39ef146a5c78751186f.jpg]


## (3) Install the caster wheel on the chassis

Use 8 pcs M3*12 screws to fix the caster wheel to the chassis.

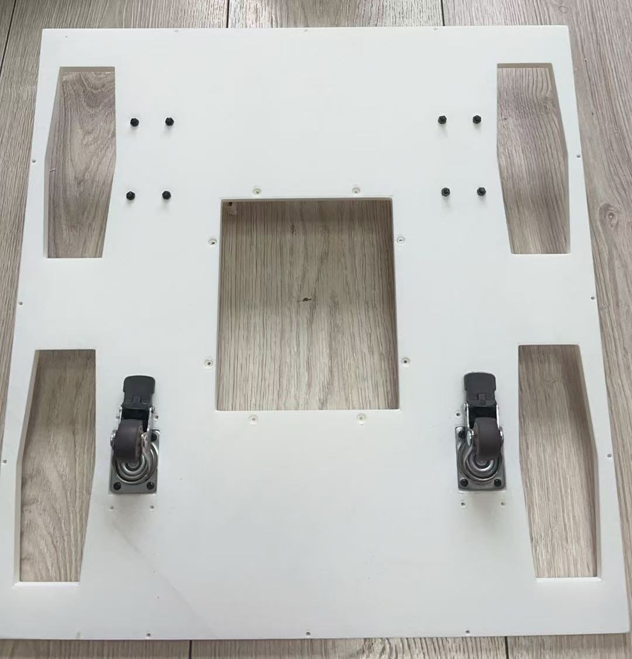
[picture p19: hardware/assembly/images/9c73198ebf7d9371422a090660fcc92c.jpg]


Note: pass the screws from bottom to top.

## (4) Install the drive wheel hubs

Slide the 37*30*4mm bearing onto the hub; the bearing should spin freely.

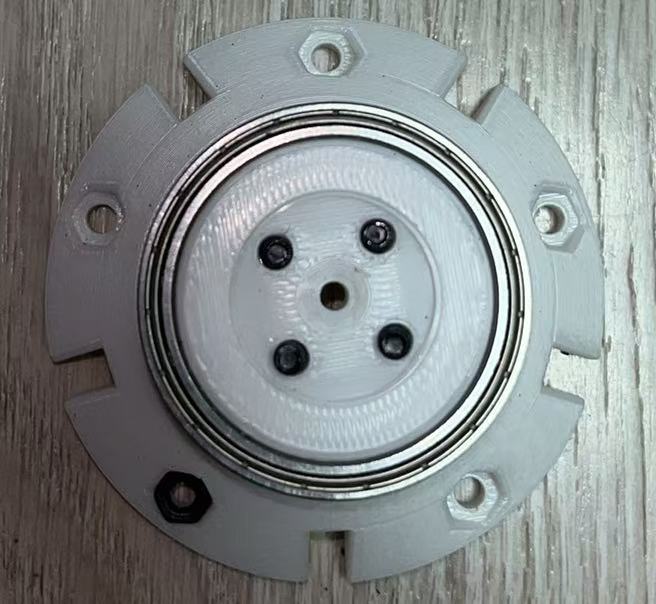
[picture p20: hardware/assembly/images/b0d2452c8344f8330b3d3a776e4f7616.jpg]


Mount the hubs onto the drive wheels using 8 pcs M3*12 screws and M3 washers
(add the M3 washers during installation).

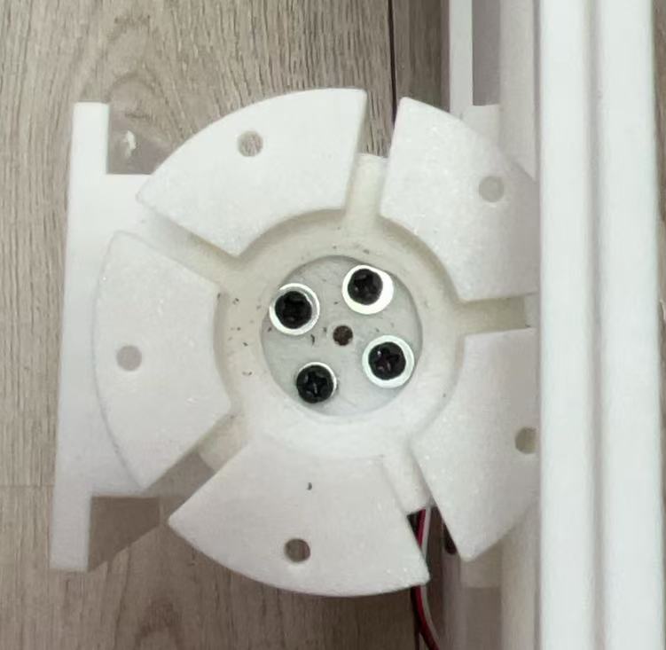
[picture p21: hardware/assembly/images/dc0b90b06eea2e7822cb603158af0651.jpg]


## (5) Install the drive wheels

Use 10 pcs M3*25 screws to mount the drive wheels onto the chassis.

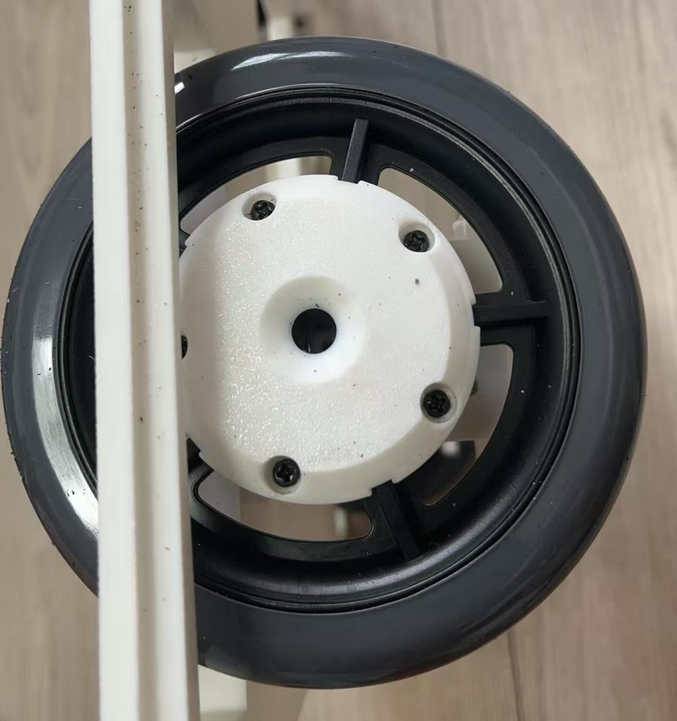
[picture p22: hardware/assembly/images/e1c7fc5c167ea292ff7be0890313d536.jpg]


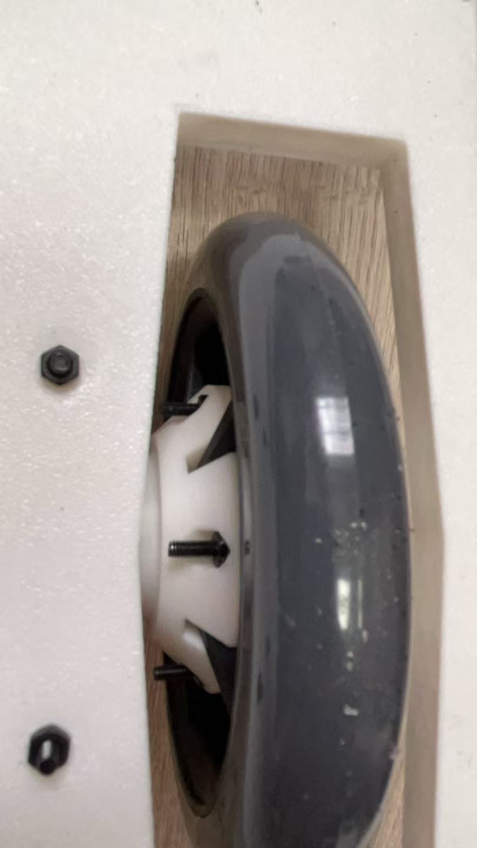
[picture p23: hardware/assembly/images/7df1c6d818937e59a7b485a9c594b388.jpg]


## (6) Set chassis servo IDs and connect servo cables

Use the FEETECH servo software to set the servo IDs: left wheel 10, right
wheel 11. Connect the servos with servo cables.

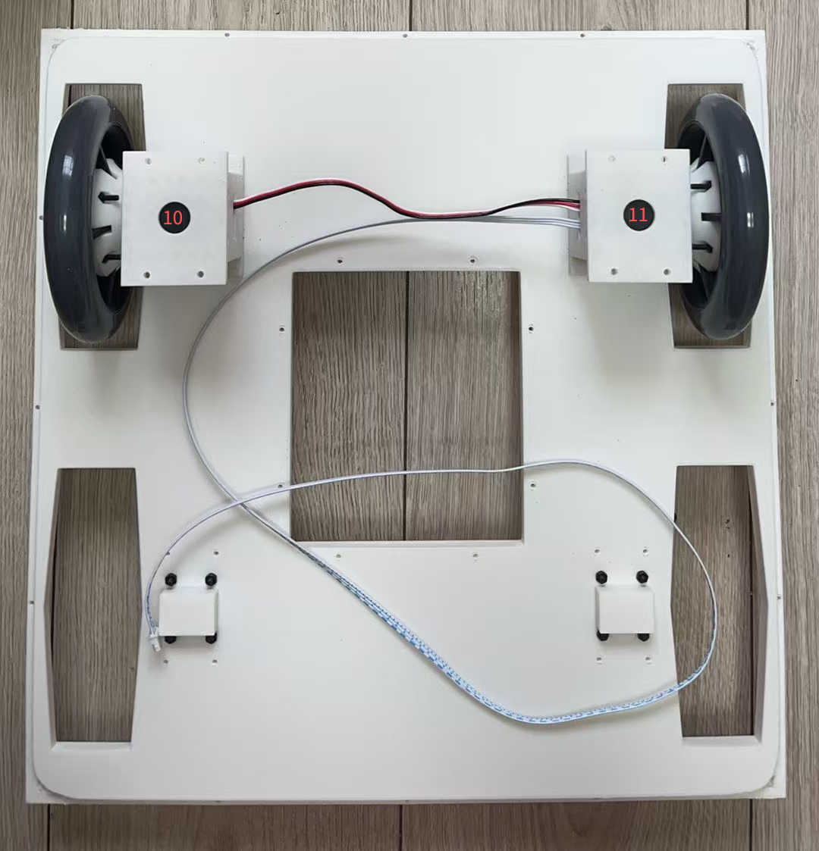
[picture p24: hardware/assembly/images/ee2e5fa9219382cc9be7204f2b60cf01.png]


## (7) Install the chassis top cover

Pass the 500mm servo cable through the hole at the front of the top cover.

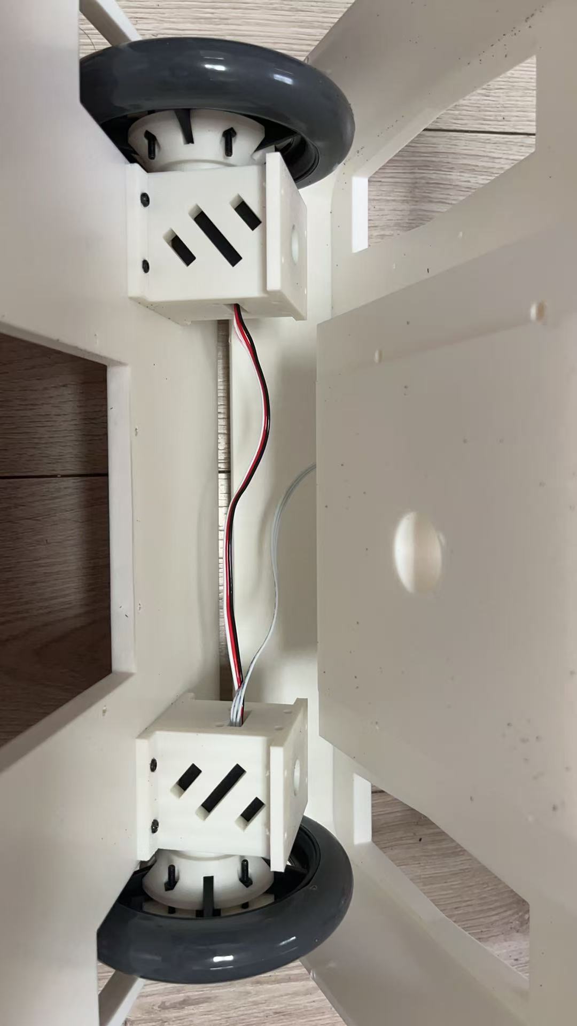
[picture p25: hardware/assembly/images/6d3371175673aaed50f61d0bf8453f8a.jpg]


Snap on the cover and tighten with 24 pcs M3*20 self-tapping screws.

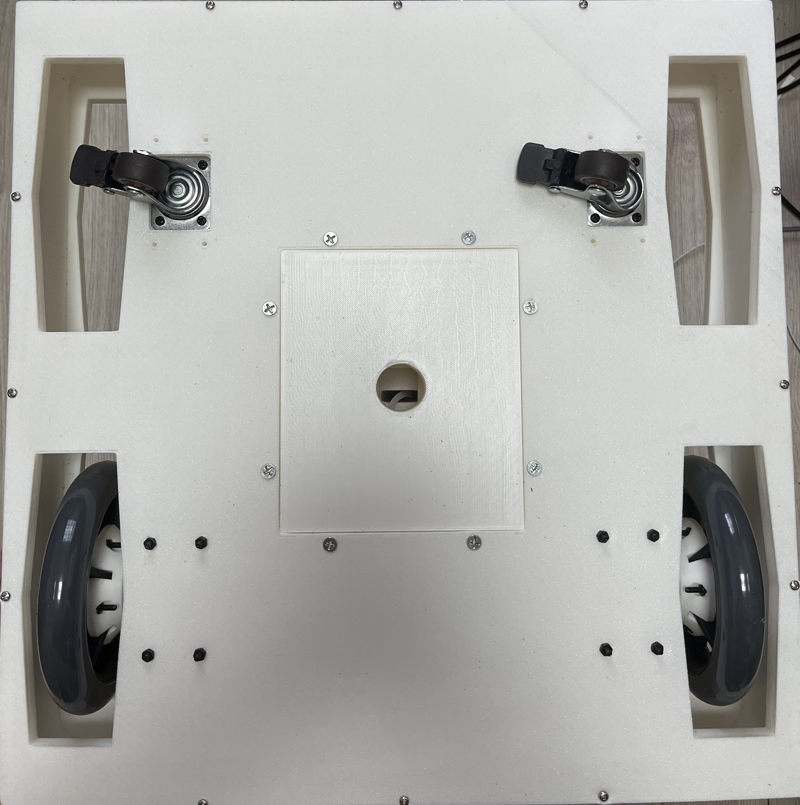
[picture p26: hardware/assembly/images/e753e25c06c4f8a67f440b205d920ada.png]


Flip the chassis over, insert the base, tighten with 8 pcs M3*22 self-tapping
screws, and route the servo cables out through the hole in the base.

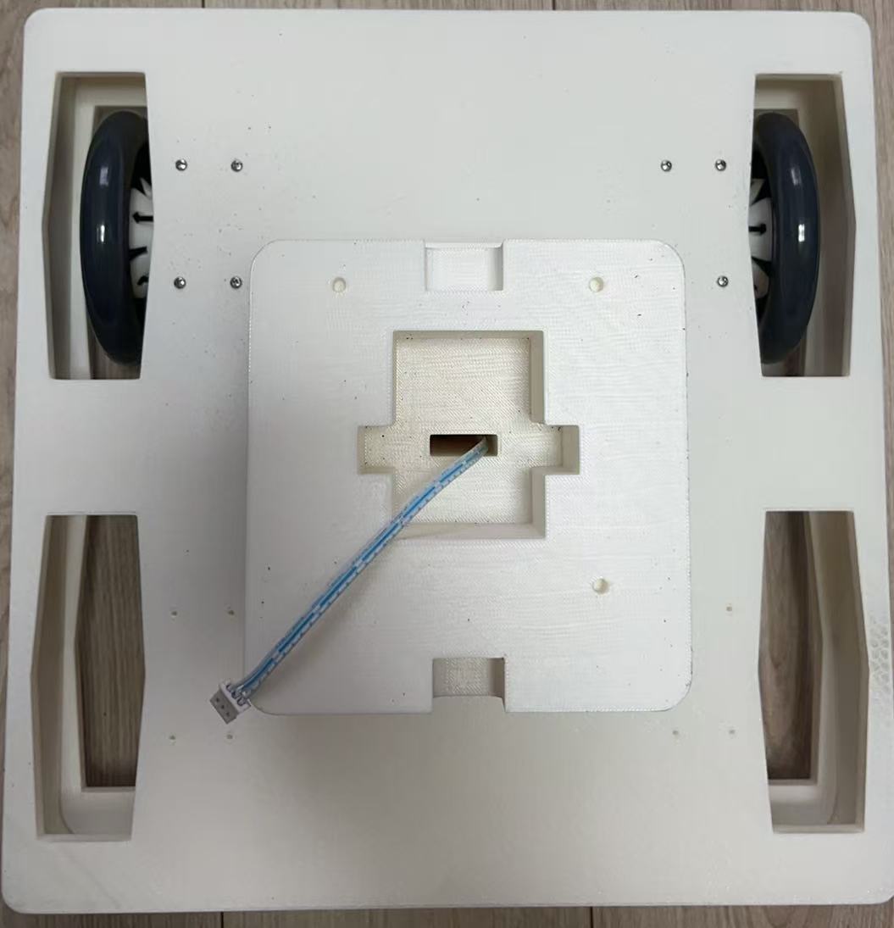
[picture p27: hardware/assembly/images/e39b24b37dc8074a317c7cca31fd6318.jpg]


# 2. Lift Axis Assembly

## (1) Install the lift servo mount

Use the FEETECH software to set the ST3250 servo ID to 9. Insert the servo into
the servo mount and tighten with screws.

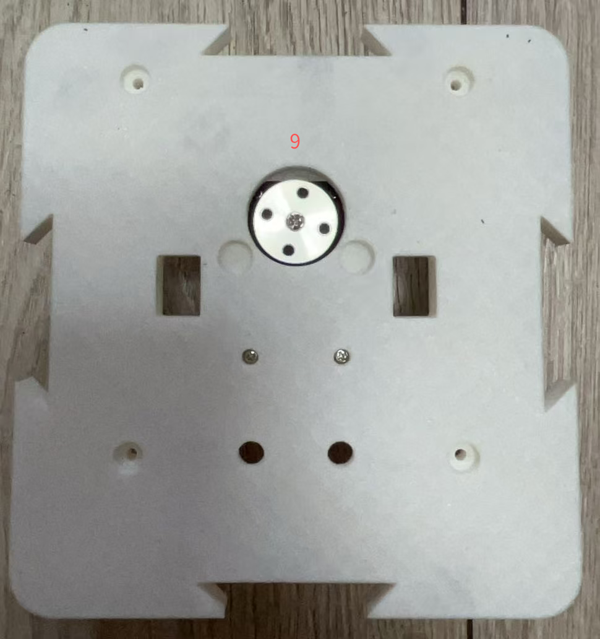
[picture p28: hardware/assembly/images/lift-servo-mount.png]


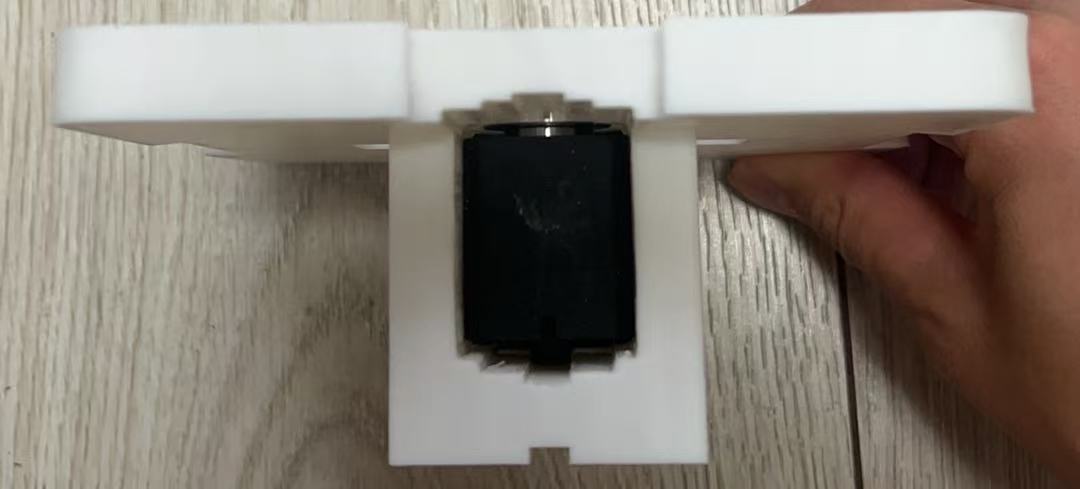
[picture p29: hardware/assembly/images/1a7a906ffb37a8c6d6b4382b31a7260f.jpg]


Install the flange onto the servo shaft.

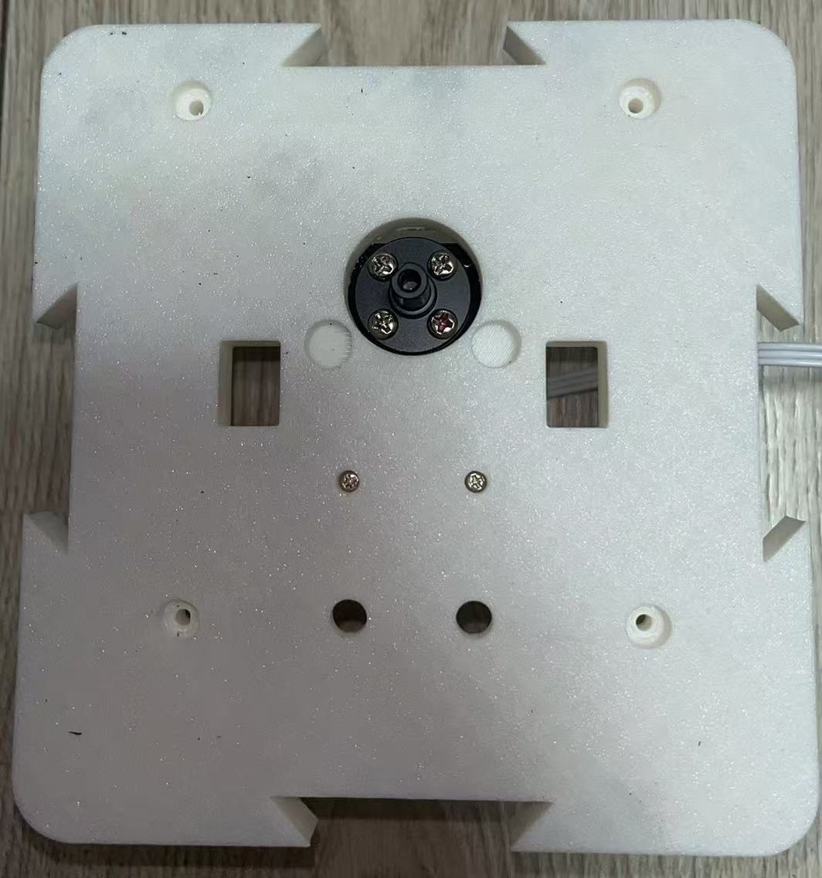
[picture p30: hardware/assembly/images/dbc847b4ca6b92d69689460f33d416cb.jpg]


## (2) Install the lift axis

Use 4 pcs M3*10 screws to fix two graphite-copper bushings and the brass nut
that comes with the lead screw onto the lift axis connector.

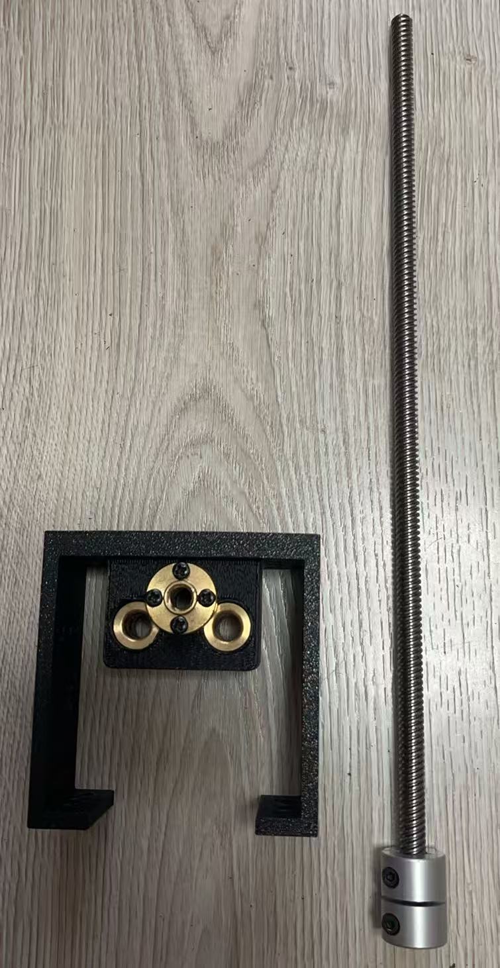
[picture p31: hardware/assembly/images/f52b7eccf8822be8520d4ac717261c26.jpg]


Pass the 300mm lead screw through the brass nut.

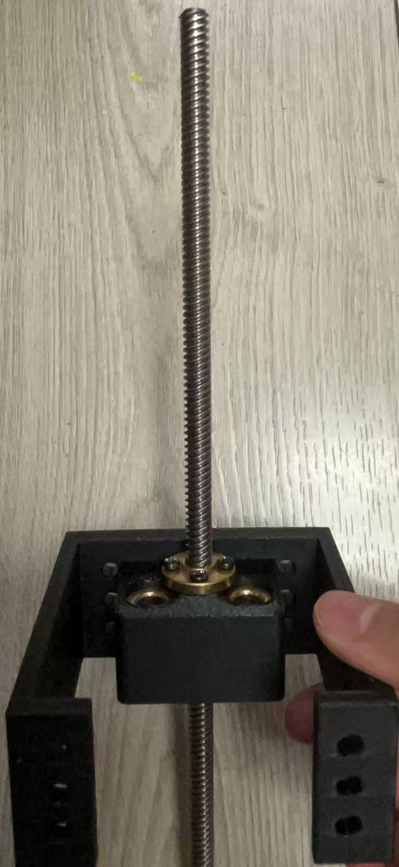
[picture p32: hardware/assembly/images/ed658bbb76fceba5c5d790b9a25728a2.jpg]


Fix the bottom of the lead screw onto the coupling and tighten with a hex key.

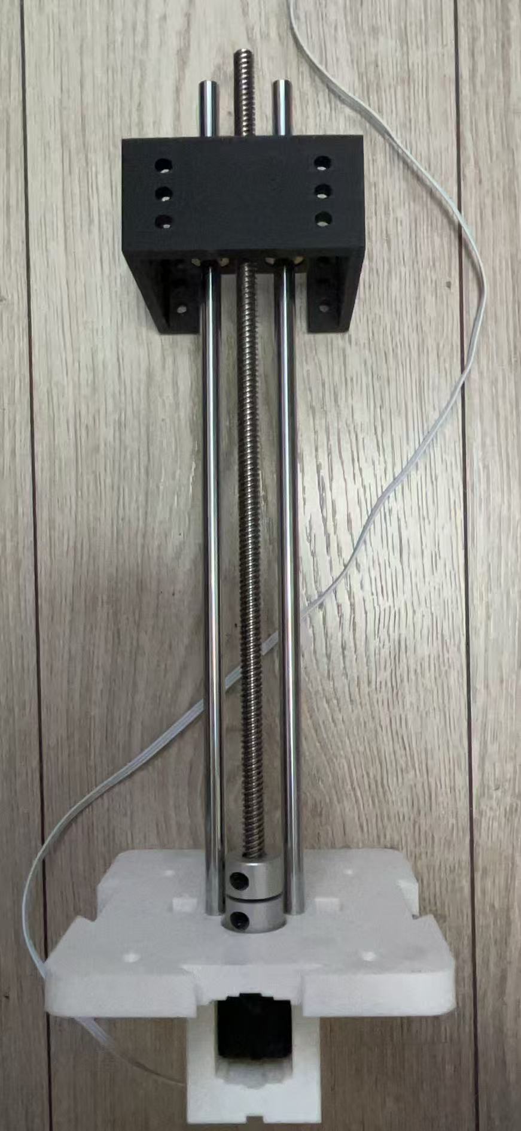
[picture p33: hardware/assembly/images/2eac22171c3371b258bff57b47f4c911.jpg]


Embed an 8 × 22 × 7mm bearing into the top printed part of the lift axis and
insert the two guide shafts into the top printed part.

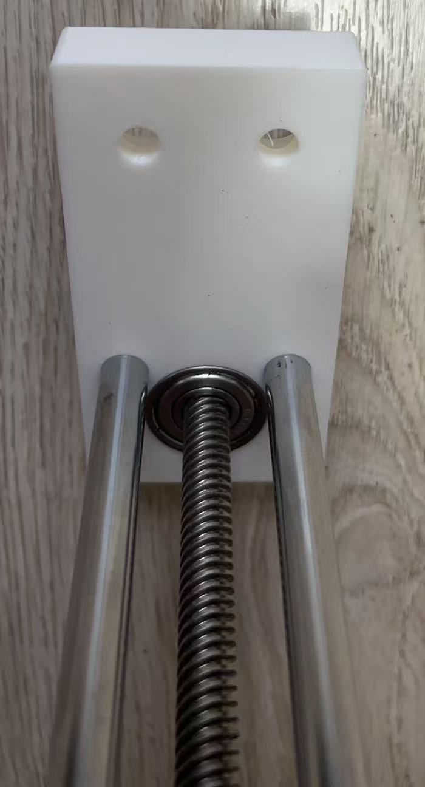
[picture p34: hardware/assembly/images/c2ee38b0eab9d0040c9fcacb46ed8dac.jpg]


Use 4 pcs M6*12 hex socket screws to fix the top and bottom of the aluminum
extrusion.

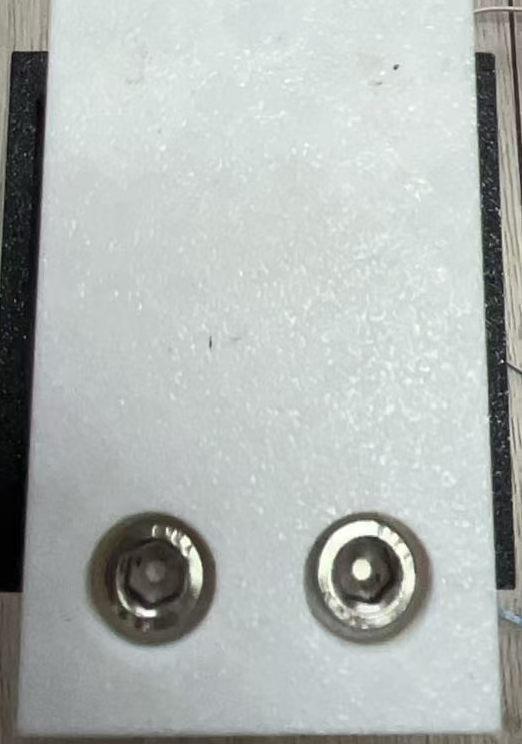
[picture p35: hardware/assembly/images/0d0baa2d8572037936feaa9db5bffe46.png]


Plug the 500mm and 1000mm servo cables that come out from the bottom into the
ST3250 servo.

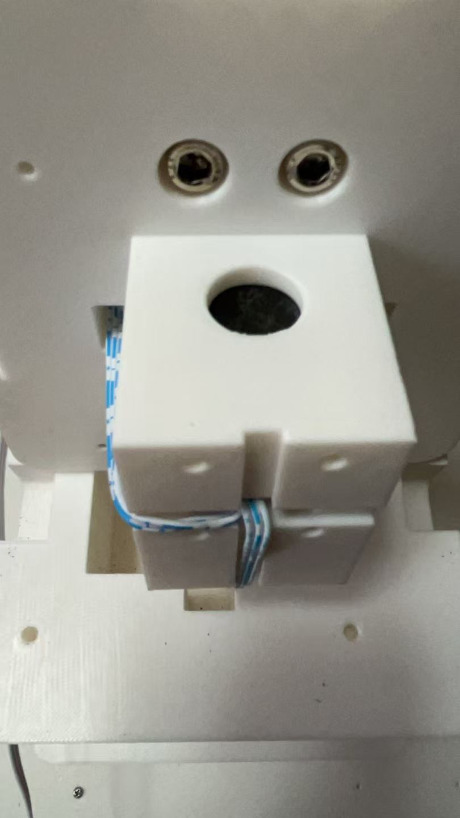
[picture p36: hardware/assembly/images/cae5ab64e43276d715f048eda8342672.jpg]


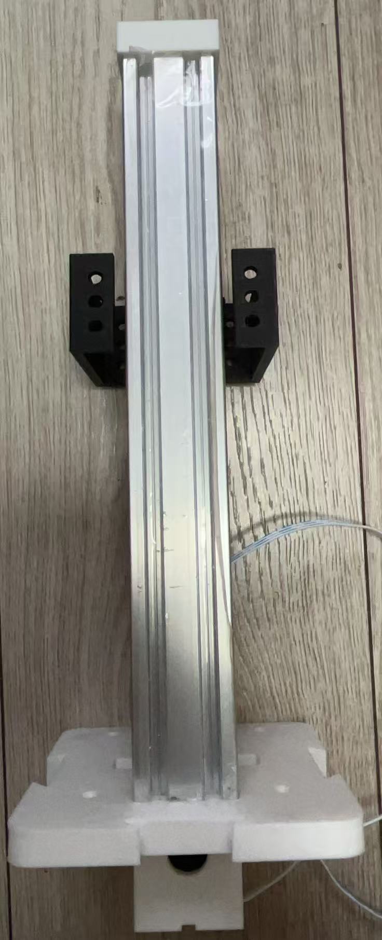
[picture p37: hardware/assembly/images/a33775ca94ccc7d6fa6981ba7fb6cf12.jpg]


Use 8–16 pcs M5*22 screws to fix the inner printed part of the lift axis onto
the lift axis. Fix the assembled lift axis onto the base and tighten with 4 pcs
M3*20 self-tapping screws.

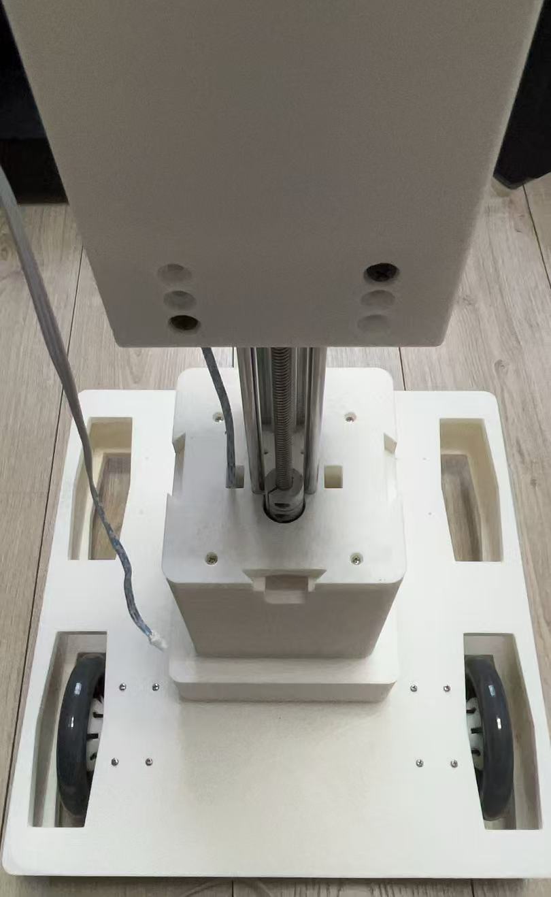
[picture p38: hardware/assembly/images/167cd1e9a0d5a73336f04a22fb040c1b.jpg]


Route the 1000mm servo cable out through the right side inside the inner
printed part.

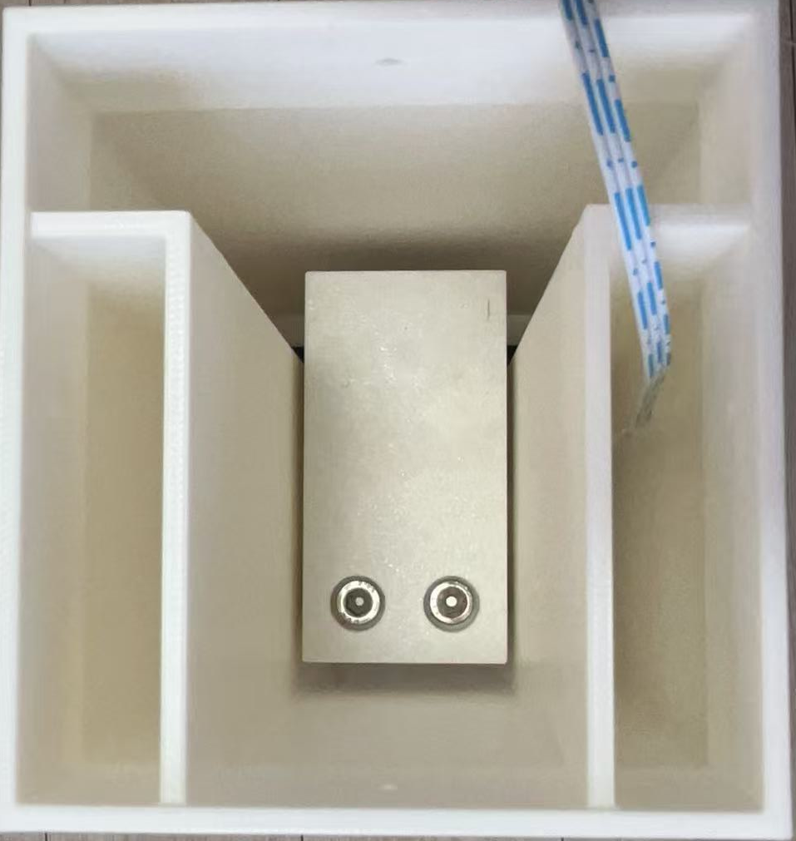
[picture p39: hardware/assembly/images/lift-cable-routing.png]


## (3) Install the lift axis outer rollers

Use 4 pcs M4*16 screws to fix 4 U-groove bearings onto the outer printed part
of the lift axis.

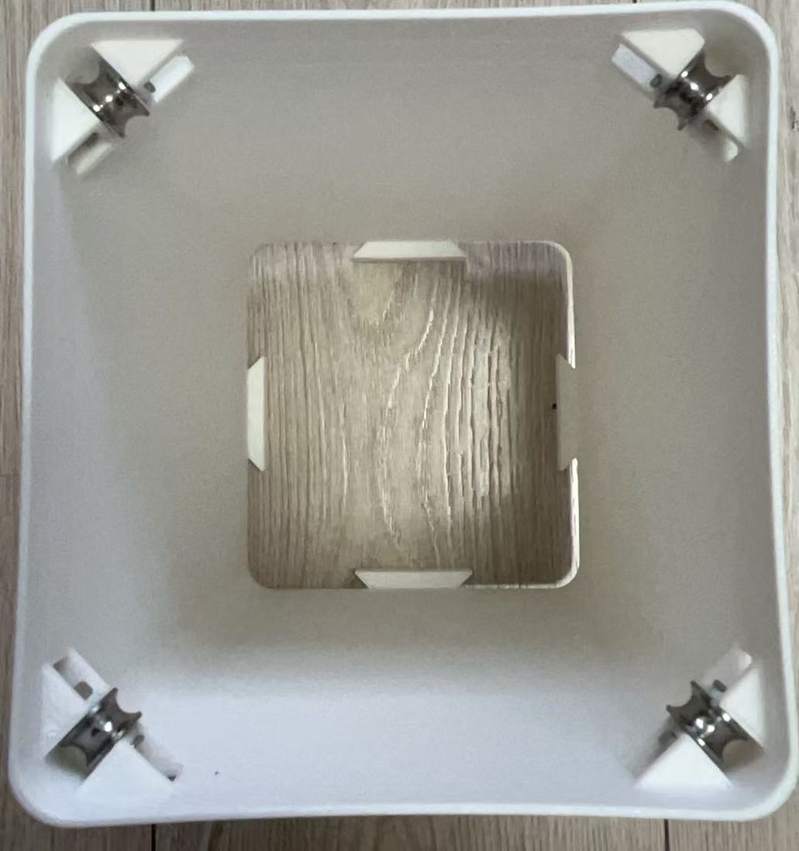
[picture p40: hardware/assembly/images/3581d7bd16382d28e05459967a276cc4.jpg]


Fix the outer printed part of the lift axis onto the base.

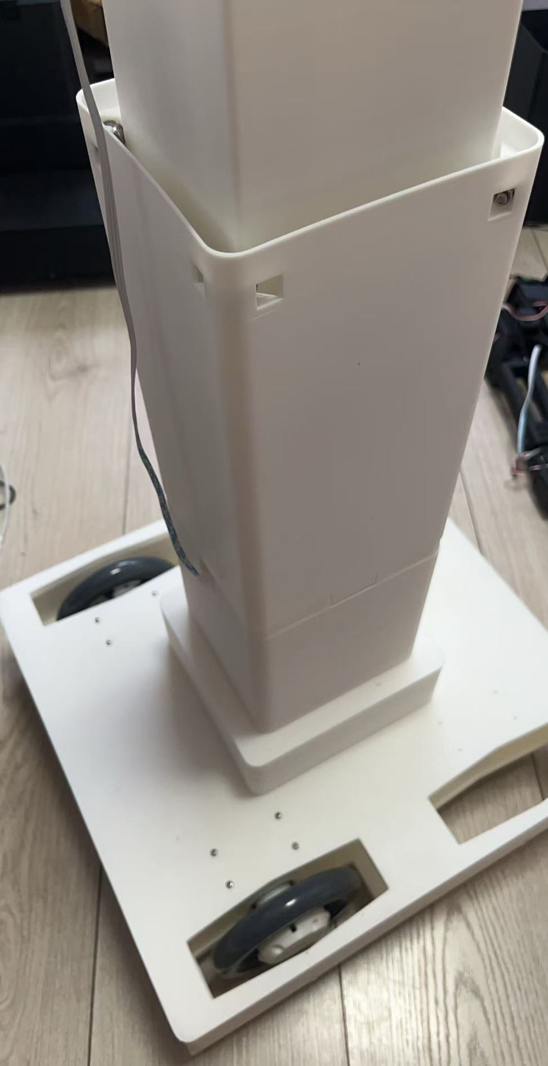
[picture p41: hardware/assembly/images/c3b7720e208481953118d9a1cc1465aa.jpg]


# 3. Arm Assembly

## (1) Follower arm assembly

Use 16 pcs ST3215 C018 servos and printed parts to assemble the follower arms.

Follower arm, right:

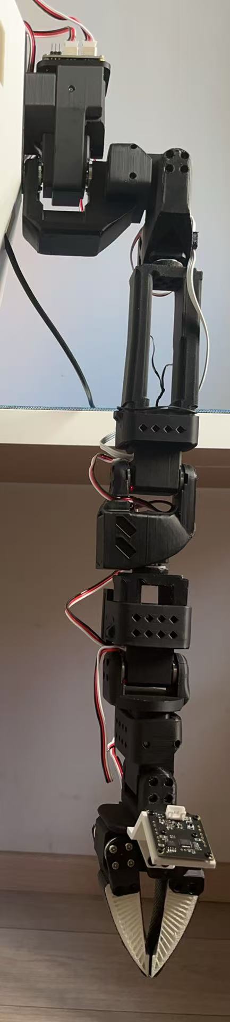
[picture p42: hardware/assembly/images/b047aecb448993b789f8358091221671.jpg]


Follower arm, left:

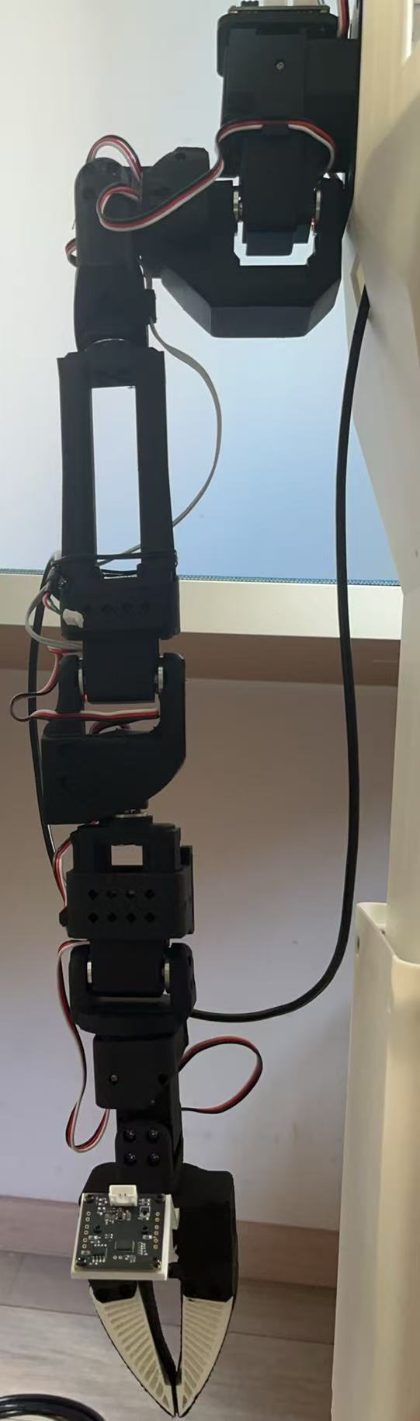
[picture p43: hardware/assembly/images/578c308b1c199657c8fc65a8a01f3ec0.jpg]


## (2) Leader arm assembly

Use 16 pcs ST3215 C046 servos and printed parts to assemble the leader arms.

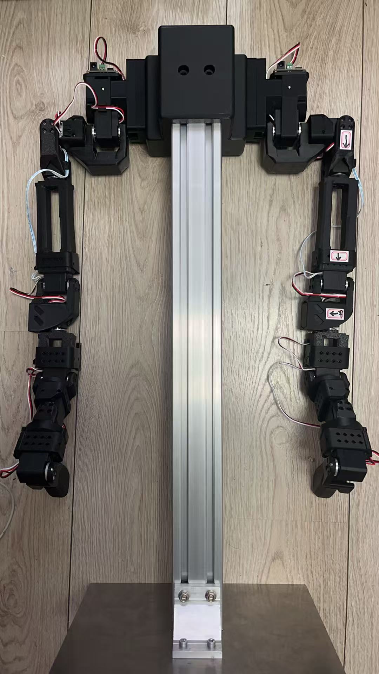
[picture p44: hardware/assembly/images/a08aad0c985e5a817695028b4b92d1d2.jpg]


Use 8 pcs M6*20 screws to fix the leader arms and the connector together, then
fix them onto the 3060 aluminum extrusion.

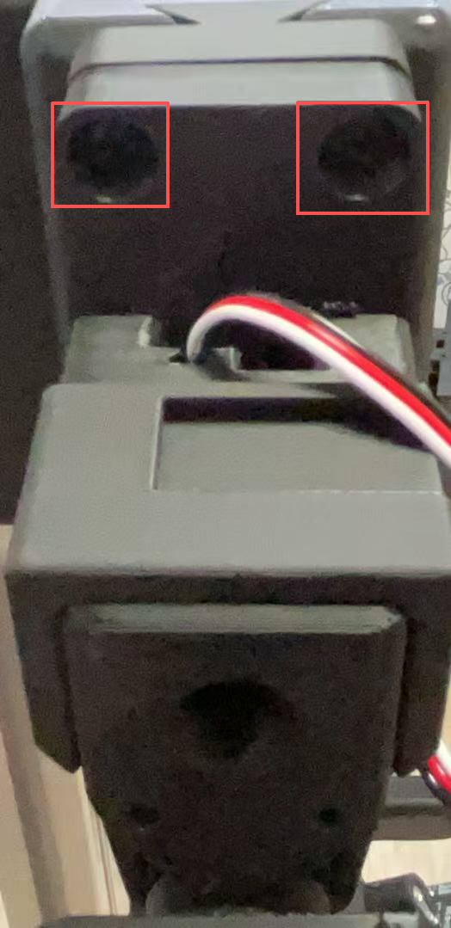
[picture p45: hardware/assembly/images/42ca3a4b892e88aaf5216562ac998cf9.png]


# 4. Body Assembly

## (1) Fix the arms

Use 8 pcs M6*22 screws to fix the arms onto the body.

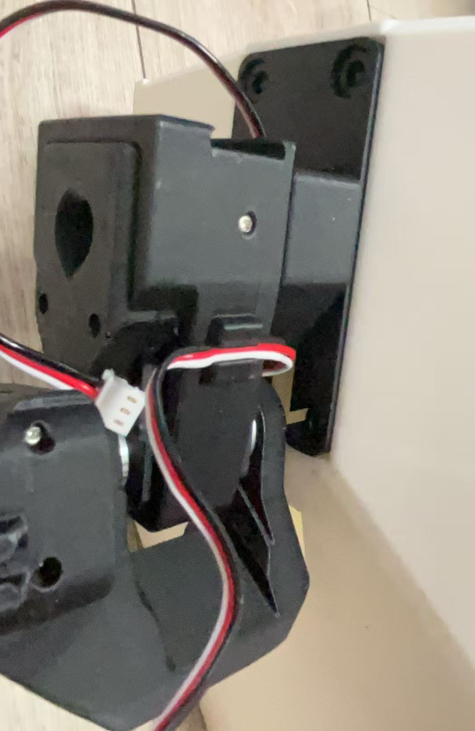
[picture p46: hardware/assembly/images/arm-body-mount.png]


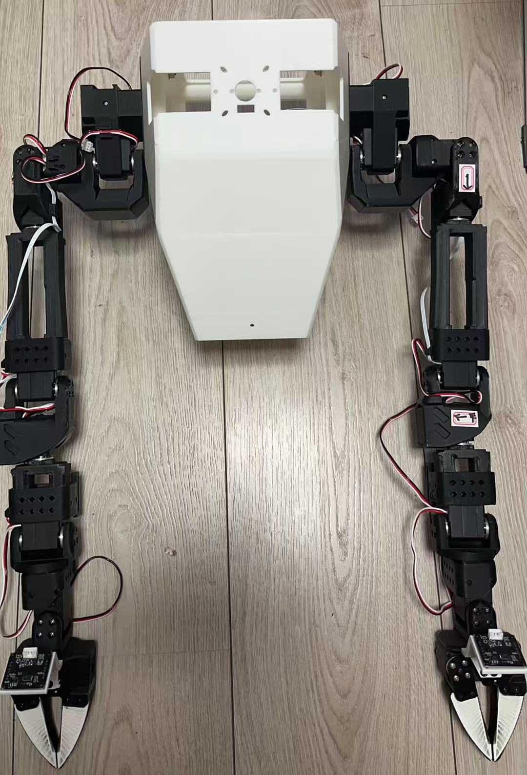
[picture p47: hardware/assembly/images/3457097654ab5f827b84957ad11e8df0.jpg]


## (2) Chest camera mount (optional)

Use 4 pcs M2*12 screws to fix the camera.

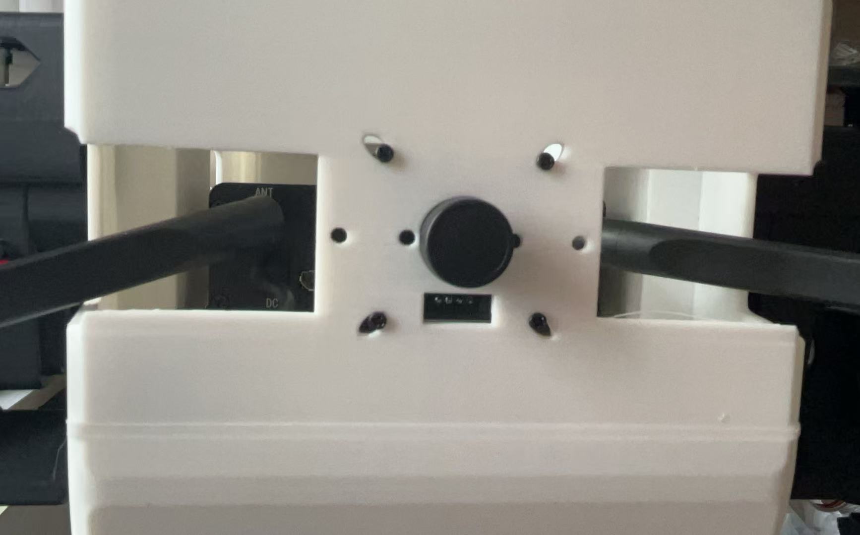
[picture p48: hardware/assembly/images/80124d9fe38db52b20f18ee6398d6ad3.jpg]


(3) Insert the body onto the lift axis and fix it with 4 pcs M3*10 self-tapping
screws.

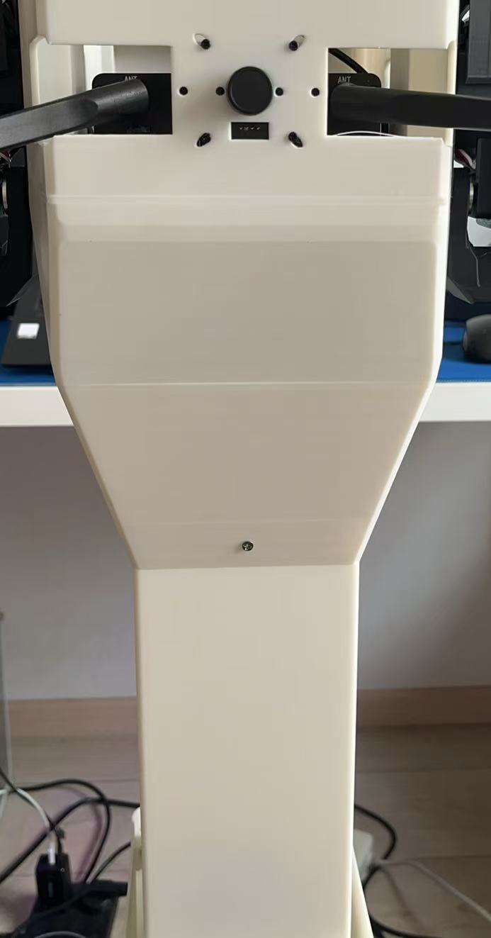
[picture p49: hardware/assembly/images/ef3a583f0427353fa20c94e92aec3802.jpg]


# 5. Neck and Head Assembly

## (1) Joint assembly

Set the IDs of the two ST3215 C018 servos (12, 13), tighten them onto the neck
printed part with the screws that come with the servos, and daisy-chain them
with servo cables.

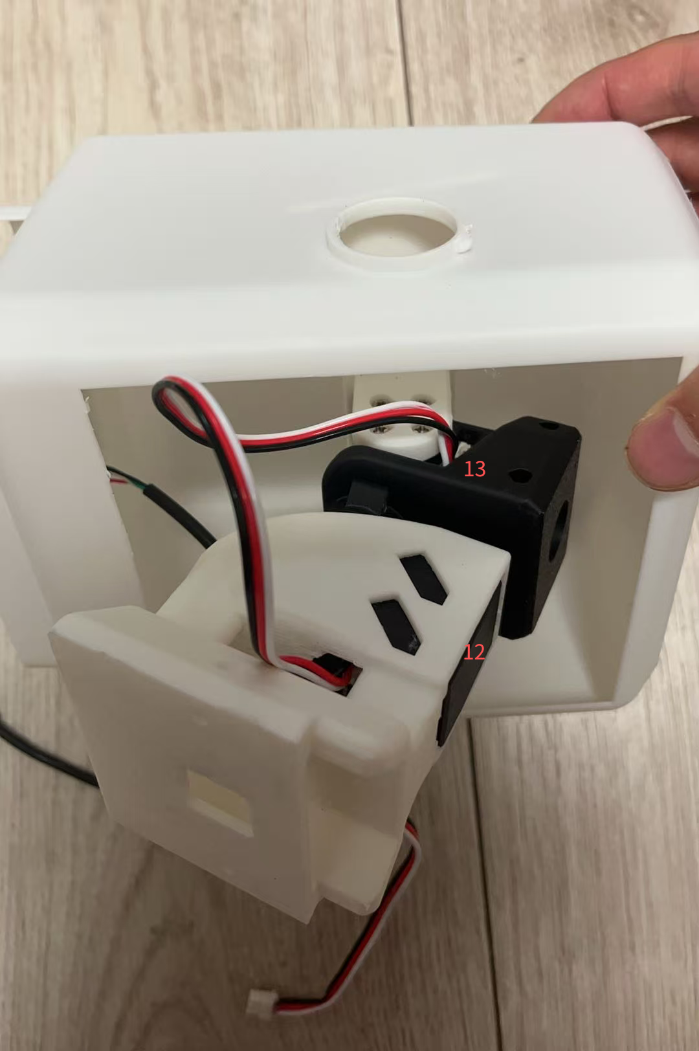
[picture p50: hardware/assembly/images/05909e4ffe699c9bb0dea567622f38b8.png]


Use the screws that come with the servos to fix the neck onto the head.

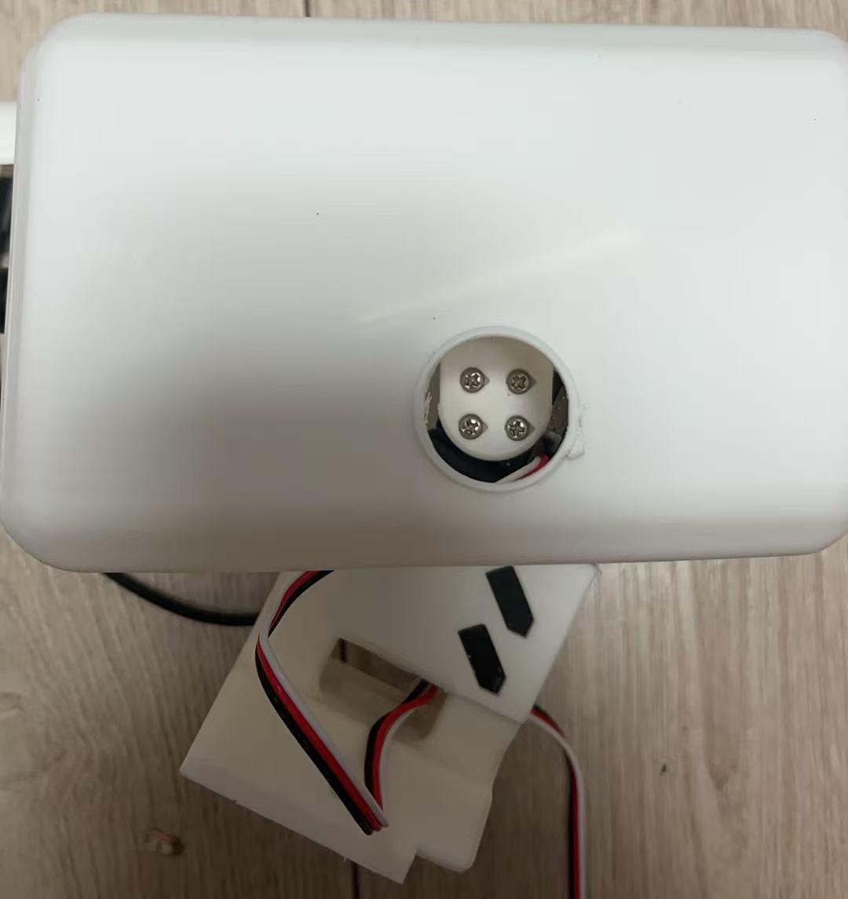
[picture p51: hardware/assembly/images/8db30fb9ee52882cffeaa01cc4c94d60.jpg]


## (2) Camera mount

Fix an RGB camera or a depth camera onto the head and connect the camera cable.

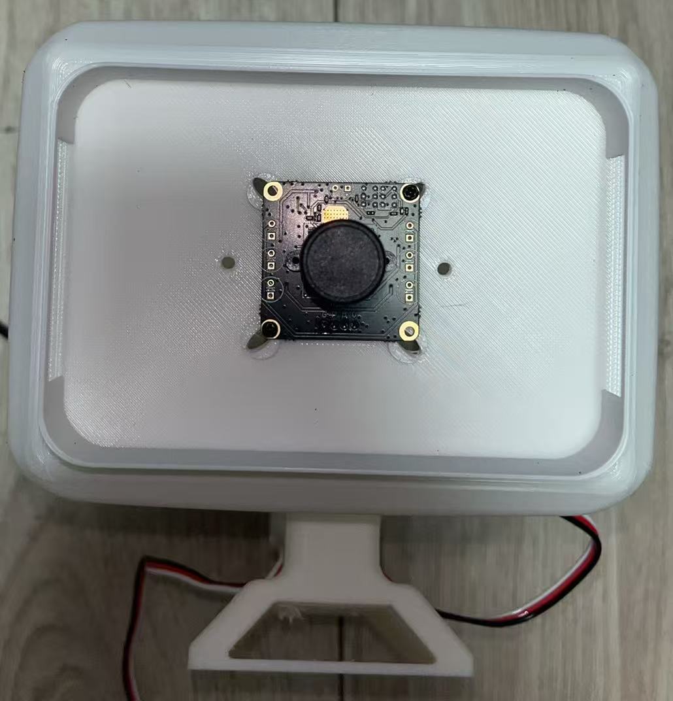
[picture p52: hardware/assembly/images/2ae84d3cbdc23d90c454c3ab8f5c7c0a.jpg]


Use 2 pcs M3*20 screws to fix the neck onto the body.

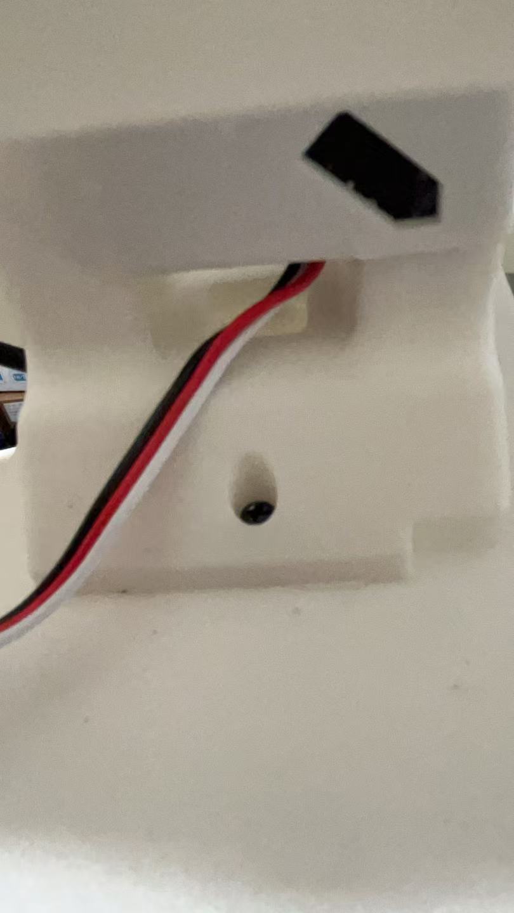
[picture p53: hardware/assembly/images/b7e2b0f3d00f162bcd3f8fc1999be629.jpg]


# 6. Display Assembly

Use 4 pcs M3.5*8 screws to fix the display and its connector.

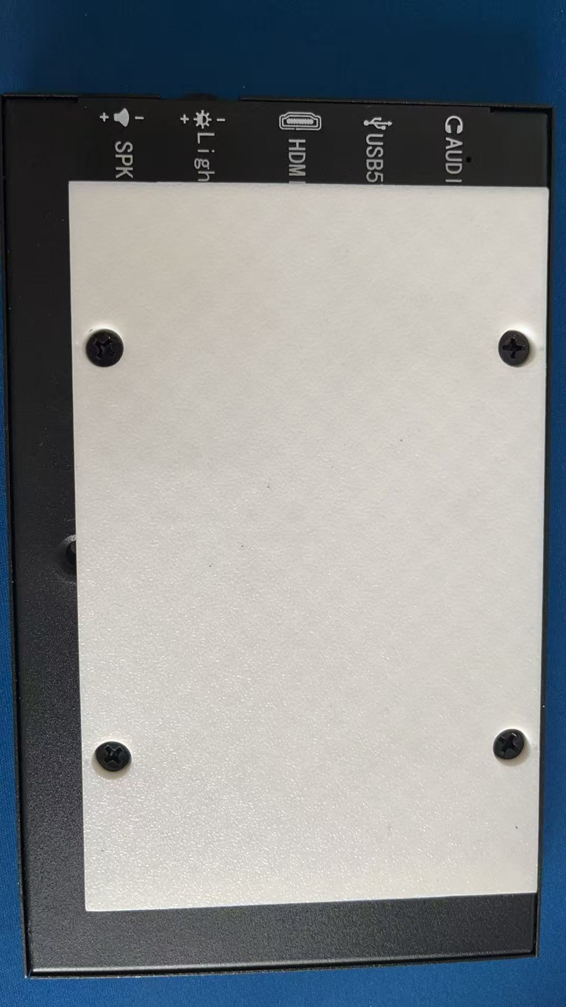
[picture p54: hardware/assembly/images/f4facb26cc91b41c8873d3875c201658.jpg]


Insert the connector into the slot on the back.

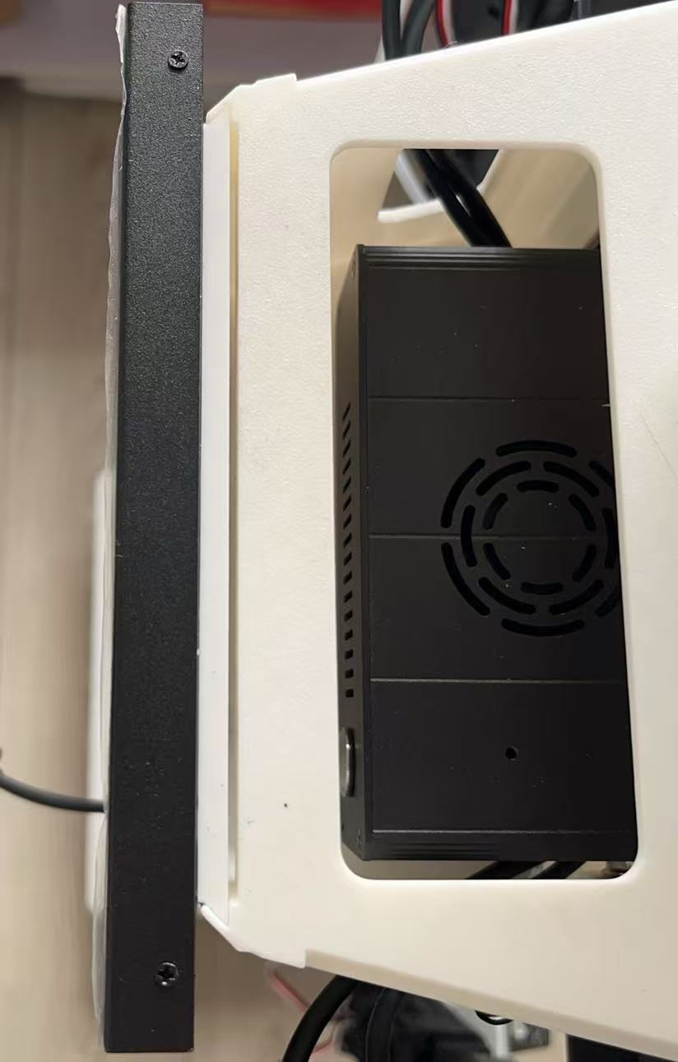
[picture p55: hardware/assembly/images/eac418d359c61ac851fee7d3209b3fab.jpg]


# 7. Wiring

Put the dock and battery on the lower level, and the Raspberry Pi or Jetson on
the upper level. (1) Use a splitter Type-C-to-DC cable to connect the battery
(140W high-power port) and the arm control board to power the arms. (2) Use
another USB-to-DC / Type-C-to-DC cable to connect the battery and the Raspberry
Pi / Jetson. (3) Plug all the cameras directly into the Raspberry Pi or Jetson.



# 8. Finished Assembly



# 9. Servo IDs and Bus Wiring

## (1) Servo ID map

| ID | Motor | Model | Bus / Port |
|----|---|---|---|
| 1–8 | Left arm (`left_arm_*`, 7-DOF + gripper) | ST3215 C018 | bus1 (`port1`) |
| 12 | Head pan | ST3215 C018 | bus1 (`port1`) |
| 13 | Head tilt | ST3215 C018 | bus1 (`port1`) |
| 1–8 | Right arm (`right_arm_*`, 7-DOF + gripper) | ST3215 C018 | bus2 (`port2`) |
| 9  | Lift (`lift_axis`) | ST3250 | bus2 (`port2`) |
| 10 | Base left wheel | ST3215 C018 | bus2 (`port2`) or bus3 |
| 11 | Base right wheel | ST3215 C018 | bus2 (`port2`) or bus3 |

> 2-bus mode (`port3=None`): the lift and wheels share bus2 with the right arm.
> 3-bus mode: the wheels move to bus3 (`port3`).

## (2) Wiring diagram (2-bus mode)

```mermaid
graph TD
    subgraph Bus1["serial bus1 (port1)"]
        LA1["left_arm 1"] --- LA8["left_arm 8"]
        LA8 --- HP["head_pan 12"]
        HP --- HT["head_tilt 13"]
    end

    subgraph Bus2["serial bus2 (port2)"]
        RA1["right_arm 1"] --- RA8["right_arm 8"]
        RA8 --- LF["lift 9 (ST3250)"]
        LF --- LW["base_left_wheel 10"]
        LW --- RW["base_right_wheel 11"]
    end

    Bus1 --> B1["to control board port1"]
    Bus2 --> B2["to control board port2"]
```

## (3) Wiring diagram (3-bus mode)

```mermaid
graph TD
    subgraph Bus1["serial bus1 (port1)"]
        A1["left_arm 1–8"] --- C1["head_pan 12 / head_tilt 13"]
    end
    subgraph Bus2["serial bus2 (port2)"]
        A2["right_arm 1–8"] --- C2["lift 9 (ST3250)"]
    end
    subgraph Bus3["serial bus3 (port3)"]
        W["base_left_wheel 10 / base_right_wheel 11"]
    end
    Bus1 --> P1["port1"]
    Bus2 --> P2["port2"]
    Bus3 --> P3["port3"]
```

> Mermaid renders automatically on GitHub. If your viewer does not render it,
> refer to the servo ID map above for the same wiring relationship.

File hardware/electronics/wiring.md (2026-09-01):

# Electronics & Wiring

Power, control board and camera wiring notes for HumanaOpen.

> Placeholder — fill in your actual wiring diagram, pinout and power notes.

## Power

- Supply voltage: **12V** (arms/servos).
- Current budget: ...

## Control board (Host)

- Board: ...
- Serial ports used: `port1` (left arm + head), `port2` (right arm), `port3` (base wheels).
- Follower connecting cables: ...

## Cameras

- `head` → `/dev/video0`
- `left_wrist` → `/dev/video2`
- `right_wrist` → `/dev/video4`
- `chest` → `/dev/video6` (optional)

See the README **Camera devices & fps** section for the tested devices.

## Wiring diagram

_(add your diagram image here)_

## Grounding / safety

- Common ground between board and servo bus.
- Fuse / polarity protection.

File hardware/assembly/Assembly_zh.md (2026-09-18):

# Assembly组装

# 1\.底盘安装

## （1）舵机固定在支架上

用舵机自带的螺丝将ST3215 C018舵机固定在舵机支架\(基座\)内



备注：将支架内部的支撑清理干净

## （2）舵机支架固定在底盘上

使用8颗 M3\*22的螺丝将ST3215 C018舵机基座固定在底盘上





## （3）在底盘安装万向论

使用8颗 M3\*12螺丝将万象轮固定在底盘上



备注：螺丝从下往上穿

## （4）安装主动轮轮毂

将37\*30\*4mm轴承套在轮毂上，轴承可以自由转动



使用8颗M3\*12螺丝和M3垫片将轮毂安装到主动轮上，安装时加入M3垫片



## （5）安装主动轮

使用10颗M3\*25的螺丝将主动轮安装到底盘上。





## （6）底盘舵机编号，连接端子线

使用飞特舵机软件给舵机编号，左轮10，右轮11。同时用端子线连接舵机。



## （7）安装底盘上盖

将500mm长端子线从上盖前面的孔穿过



扣上盖子，使用24颗 M3\*20的自攻螺丝拧紧\.



翻转底盘，插入基座，并用8颗 M3\*22自攻螺丝拧紧，端子线从基座孔穿出



# 2\.升降轴安装

## （1）升降轴舵机座安装

使用FEETECH软件给ST 3250舵机编号9。将舵机插进舵机座并用螺丝拧紧





将法兰盘安装在舵机轴上



## （2）升降轴安装

使用4颗M3\*10螺丝将两个石墨铜衬轴承和丝杠自带的铜螺母固定在升降轴连接件上



将300mm丝杠从铜螺母中穿过



将丝杠底部固定在联轴器上，使用内六角螺丝刀拧紧



在升降轴顶部打印件嵌入8 × 22 × 7mm轴承，将两根光轴插入顶部打印件



使用四颗M6\*12内六角螺丝固定铝型材顶部和底部



将底部穿出的500mm端子线和1000mm端子线插在ST3250舵机上





使用8～16颗M5\*22螺丝将升降轴内侧打印件固定在升降轴上。将拼装好的升降轴固定在底座上，并用4颗M3\*20自攻螺丝拧紧



将1000mm端子线从内侧打印件内部右侧穿出



## （3）升降轴外侧滑轮安装

使用4颗 M4\*16螺丝将4个U型槽轴承固定在升降轴外侧打印件上



将升降轴外侧打印件固定在基座上



# 3\.机械臂安装

## （1）从臂安装

使用16个ST3215 C018舵机和打印件安装从臂

从臂右臂



从臂左臂



## （2）主臂安装

使用16个ST3215 C046舵机和打印件安装主臂



使用8颗M6\*20螺丝将主臂和连接件固定在一起，并固定在3060铝型材上。



# 4\.身体安装

## （1）机械臂固定

使用8颗M6\*22螺丝将机械臂固定在身体上





## （2）胸部相机固定（可选）

使用4颗M2\*12的螺丝固定相机



（3）将身体插入升降轴上，并用4颗M3\*10自攻螺丝固定



# 5\.颈部和头部安装

## （1）关节安装

将两个ST3215 C018舵机编号（12,13），使用舵机自带螺丝拧紧在颈部打印件上并通过舵机线串联。



使用舵机自带螺丝将颈部固定在头部



## （2）相机固定

将RGB相机或者深度相机固定在头部，并插入相机线



使用两颗M3\*20螺丝将颈部固定在身体上



# 6\.显示屏安装

使用4颗M3\.5\*8螺丝固定显示屏和连接器



将连接器插入背部卡槽



# 7\.接线

下层装拓展坞和电池，上层装树莓派或Jetson。（1）使用一分二的TypeC转DC线连接电池（140W大功率接口）和机械臂的控制板给机械臂供电。（2）使用另一根USB转DC/TypeC转DC连接电池和树莓派/Jetson。（3）将所有相机单独插在树莓派或Jetson上。



# 8\.组装成品



# 9\.舵机编号与总线接线

## （1）舵机编号总表

| ID | 舵机 | 型号 | 总线 / 端口 |
|----|---|---|---|
| 1–8 | 左臂（`left_arm_*`，7 自由度 + 夹爪） | ST3215 C018 | bus1（`port1`） |
| 12 | 头部俯仰（pan） | ST3215 C018 | bus1（`port1`） |
| 13 | 头部偏航（tilt） | ST3215 C018 | bus1（`port1`） |
| 1–8 | 右臂（`right_arm_*`，7 自由度 + 夹爪） | ST3215 C018 | bus2（`port2`） |
| 9  | 升降轴（`lift_axis`） | ST3250 | bus2（`port2`） |
| 10 | 底盘左轮 | ST3215 C018 | bus2（`port2`）或 bus3 |
| 11 | 底盘右轮 | ST3215 C018 | bus2（`port2`）或 bus3 |

> 2-bus 模式（`port3=None`）：升降轴和轮子与右臂共用 bus2。
> 3-bus 模式：轮子移到 bus3（`port3`）。

## （2）接线图（2-bus 模式）

```mermaid
graph TD
    subgraph Bus1["serial bus1 (port1)"]
        LA1["left_arm 1"] --- LA8["left_arm 8"]
        LA8 --- HP["head_pan 12"]
        HP --- HT["head_tilt 13"]
    end

    subgraph Bus2["serial bus2 (port2)"]
        RA1["right_arm 1"] --- RA8["right_arm 8"]
        RA8 --- LF["lift 9 (ST3250)"]
        LF --- LW["base_left_wheel 10"]
        LW --- RW["base_right_wheel 11"]
    end

    Bus1 --> B1["to control board port1"]
    Bus2 --> B2["to control board port2"]
```

## （3）接线图（3-bus 模式）

```mermaid
graph TD
    subgraph Bus1["serial bus1 (port1)"]
        A1["left_arm 1–8"] --- C1["head_pan 12 / head_tilt 13"]
    end
    subgraph Bus2["serial bus2 (port2)"]
        A2["right_arm 1–8"] --- C2["lift 9 (ST3250)"]
    end
    subgraph Bus3["serial bus3 (port3)"]
        W["base_left_wheel 10 / base_right_wheel 11"]
    end
    Bus1 --> P1["port1"]
    Bus2 --> P2["port2"]
    Bus3 --> P3["port3"]
```

> Mermaid 在 GitHub 上自动渲染；如果查看器不渲染，可对照上面的舵机编号总表。

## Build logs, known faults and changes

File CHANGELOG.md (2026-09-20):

# Changelog

All notable changes to **HumanaOpen** are documented here. Format loosely
follows [Keep a Changelog](https://keepachangelog.com/); this project is
pre-1.0 so breaking changes may occur until a stable release.

## [Unreleased]

### Added
- **Arm/head tremor suppression (leader + follower jitter lock)**:
  - `leader.py`: speed-adaptive EMA (`alpha_min`, `alpha_speed_ref`) replaces
    the fixed 0.35 alpha — the arm freezes at rest and stays responsive during
    fast moves.
  - `leader.py`: output deadband (`deadband=0.1` ≈ 2 encoder ticks): the
    emitted action holds its last value until the smoothed signal actually
    moves, so stationary encoder self-noise (±0.1) never reaches the follower.
    Gripper gets the same deadband (no EMA).
  - `humanaopen.py`: follower write deadband (`goal_deadband=0.1`): targets
    whose delta from the last written value is below the band are skipped
    (existing wheel-dedup pattern), so a still arm issues zero servo writes —
    no re-planning, no bus traffic, no micro-motion.
  - New tunables in `leader.py` / `config_humanaopen.py`:
    `alpha_min=0.15`, `alpha_speed_ref=1.0`, `deadband=0.1`,
    `goal_deadband=0.1` — all optional, values above are the backward-
    compatible defaults.
  - Mock-verified: `tests/test_leader_jitter.py` (run without hardware) proves
    stationary output stays bit-identical under ±0.1 noise over 2000 frames,
    fast steps are tracked in ~0.3s, and slow ramps never drift.
- **`teleop_leader_to_follower.py`: command-line bus-topology switch**
  (`--robot.port1/port2/port3`). `--robot.port3 None` (default) keeps the
  2-bus layout (wheels+lift on port2); passing a device name (e.g.
  `--robot.port3 /dev/ttyACM2`) moves lift+wheels to a dedicated third bus —
  right arm gets an uncontended bus2 (cleaner 60Hz frame timing, less
  move-start latency). Same `None` string parsing as `record_data.py` /
  `eval_data.py`.
- **`humanaopen_host_launcher.py`: command-line Host startup** for
  dual-machine (ZMQ) mode. Same flag style as the other scripts:
  `--robot.port1/port2/port3` (`None` = 2-bus, any device name = 3-bus),
  `--no-cameras` (pure control, no video), and per-camera overrides
  (`--head-camera`, `--left-wrist-camera`, `--right-wrist-camera`,
  `--chest-camera`). Covers all four 2-bus/3-bus × cameras on/off
  combinations without editing a `python3 -c` one-liner. All four READMEs
  updated to recommend it (inline form kept as equivalent alternative).
- Dual-machine (ZMQ) data collection and inference examples in all four READMEs.
- Unified `--display=rerun|foxglove` display flag across teleop / record / eval
  (omit `--display` for headless; `--display=foxglove` auto-opens the web viewer).
- `--enable-base` and `--enable-lift` switches for policy inference
  (`--enable-lift` holds the lift at its current height by default).
- Base auto-stop on inference exit: ZMQ CONFLATE-safe stop ordering + a Host
  watchdog that zeroes the wheels after `watchdog_timeout_ms` with no command.
- Foxglove visualization backend for teleop / record / eval.
- `hardware/` directory: BOM, assembly, CAD (Fusion 360 + STEP), STL, URDF,
  electronics wiring.
- CAD STEP exports (36 files): `hardware/cad/step/HumanaOpen_step/` (16 parts:
  chassis, torso, head, lift) and `hardware/cad/step/Open-arms-mini_step/`
  (20 parts: J1-J8 arm joints, holders, trigger, WaveShare plate).
- 3D-print STL files (38 files): `hardware/stl/HumanaOpen_stl/` (17 parts) and
  `hardware/stl/Open-arms-mini-stl/` (21 parts), in mm, revision-named.
- Complete robot URDF: `hardware/urdf/humanaopen.urdf` — full kinematic tree
  (base wheels, lift, torso, head pan/tilt, 2× 7-DOF arm + gripper) with 26
  STL meshes in `hardware/urdf/meshes/`, collision boxes, and estimated
  inertial. Joint names mirror `lerobot_robot_humanaopen/humanaopen.py`.
- **Language-driven navigation** (`examples/lightnav_navigation.py`): LightNav-0
  vision-language-action model on a GPU PC drives the base through a lightweight
  ZMQ adapter — no LightNav install / ROS / lidar / map on the robot. Uses the
  official `waypoint_command` control law + RVQ-quantization deadbands
  (fail-safe zero on stop/disconnect). Real-robot verified: straight walk
  0.113 m/s, left-turn arc, exact idle zero. English instructions only.
  Docs: `docs/navigation/lightnav_integration.md`.

### Fixed
- Teleop native Rerun (`--display`) now logs on the main control thread to avoid
  gRPC backpressure / frozen viewer.
- `--display` no longer prefix-matched to `--display-foxglove` (added explicit
  `--display` argument).
- Lift would appear to "not move": `Acceleration` (SRAM) resets to 0 on every
  power cycle, capping commanded speed at ~10-20% of target; lift
  `configure()` now writes `Acceleration=254` (fastest ramp) on every connect.
- Lift would silently run 50x slower than commanded when the servo `Phase`
  register BIT2 was 1 (1 step/s/raw) while all speed constants assume BIT2=0
  (50 step/s/raw). `configure()` now reads `Phase` and switches BIT2 to 0
  (EPROM write, survives reboot) automatically — no manual
  `examples/switch_phase_bit2.py` needed after firmware re-flash.
- Stale lift zero file after a servo replacement: `restore_zero()` now checks
  `Model_Number` (different-motor detection) and a triangle-consistency check
  (`(cur - abs_tick_at_home) mod rev == extended_ticks mod rev`) that catches
  same-model swaps even when the raw encoder tick coincidentally matches.
  A stale zero file now invalidates automatically → re-home, no manual
  `rm lift_zero.json` needed.
- Dual-machine teleop latency overhaul: host control loop 30→60Hz
  (`max_loop_freq_hz=60`) and teleop `--fps` option (halves the 2-frame
  pipeline delay ~66ms→~33ms); host drains the command queue each frame and
  applies only the newest so stale commands never replay after a stall; teleop
  reads both leader arms concurrently (two serial buses in parallel); serial
  retries removed from the hot path (a flaky sync_read no longer stalls the
  whole 30/60Hz loop up to 140ms); client PUSH `SNDTIMEO=10ms` + send
  fault-tolerance so a stalled peer never freezes the loop; lift bus-write
  failures no longer crash the host. Latency display rewritten as a **skew-free
  command→obs RTT**: every command carries the client's `perf_counter_ns`, the
  host echoes it in the next observation, and the client computes RTT on its
  own monotonic clock — immune to cross-machine wall-clock skew (the old
  `net:` reading was meaningless, often negative).

## [0.1.0] - 2026-09

Initial open-source release.

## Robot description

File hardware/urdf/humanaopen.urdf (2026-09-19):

<?xml version='1.0' encoding='utf-8'?>
<robot name="humanaopen">

  <link name="base_link">
    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
    <inertial>
      <origin xyz="0 0 -0.01" rpy="0 0 0" />
      <mass value="2.0" />
      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
    </inertial>
  </link>

  
  <joint name="base_left_wheel_joint" type="continuous">
    <parent link="base_link" />
    <child link="base_left_wheel" />
    <origin xyz="0.09 0.0 0.032" rpy="0 0 0" />
    <axis xyz="0 1 0" />
  </joint>
  <link name="base_left_wheel">
    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
    <inertial>
      <origin xyz="0 0 0" rpy="0 0 0" />
      <mass value="0.15" />
      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
    </inertial>
  </link>

  <joint name="base_right_wheel_joint" type="continuous">
    <parent link="base_link" />
    <child link="base_right_wheel" />
    <origin xyz="-0.09 0.0 0.032" rpy="0 0 0" />
    <axis xyz="0 1 0" />
  </joint>
  <link name="base_right_wheel">
    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
    <inertial>
      <origin xyz="0 0 0" rpy="0 0 0" />
      <mass value="0.15" />
      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
    </inertial>
  </link>

  
  <link name="lift_base">
    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
    <inertial>
      <origin xyz="0 0 0.155" rpy="0 0 0" />
      <mass value="0.6" />
      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
    </inertial>
  </link>
  <joint name="lift_base_joint" type="fixed">
    <parent link="base_link" />
    <child link="lift_base" />
    <origin xyz="0 0 0.08" rpy="0 0 0" />
  </joint>

  <joint name="lift_axis" type="prismatic">
    <parent link="lift_base" />
    <child link="lift_carriage" />
    <origin xyz="0 0 0.25" rpy="0 0 0" />
    <axis xyz="0 0 1" />
    <limit lower="0.003" upper="0.200" effort="30" velocity="0.2" />
  </joint>
  <link name="lift_carriage">
    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
    <inertial>
      <origin xyz="0 0 0" rpy="0 0 0" />
      <mass value="0.5" />
      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
    </inertial>
  </link>

  
  <link name="torso">
    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
    <inertial>
      <origin xyz="0 0 0" rpy="0 0 0" />
      <mass value="1.5" />
      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
    </inertial>
  </link>
  <joint name="torso_joint" type="fixed">
    <parent link="lift_carriage" />
    <child link="torso" />
    <origin xyz="0 0 0.28" rpy="0 0 0" />
  </joint>

  
  <link name="head_pan_link">
    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
    <inertial>
      <origin xyz="0 0 0" rpy="0 0 0" />
      <mass value="0.1" />
      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
    </inertial>
  </link>
  <joint name="head_pan" type="revolute">
    <parent link="torso" />
    <child link="head_pan_link" />
    <origin xyz="0 0 0.52" rpy="0 0 0" />
    <axis xyz="0 0 1" />
    <limit lower="-3.14159" upper="3.14159" effort="10" velocity="1.0" />
  </joint>

  <link name="head_tilt_link">
    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
    <inertial>
      <origin xyz="0.02 0 0" rpy="0 0 0" />
      <mass value="0.25" />
      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
    </inertial>
  </link>
  <joint name="head_tilt" type="revolute">
    <parent link="head_pan_link" />
    <child link="head_tilt_link" />
    <origin xyz="0 0 0.03" rpy="0 0 0" />
    <axis xyz="0 1 0" />
    <limit lower="-3.14159" upper="3.14159" effort="10" velocity="1.0" />
  </joint>

  
  
  <joint name="left_arm_shoulder_pan_joint" type="revolute">
    <parent link="torso" />
    <child link="left_arm_shoulder_pan_link" />
    <origin xyz="0.115 0 0.42" rpy="0 0 0" />
    <axis xyz="0 0 1" />
    <limit lower="-2.967" upper="2.967" effort="30" velocity="2.0" />
  </joint>
  <link name="left_arm_shoulder_pan_link">
    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
    <inertial>
      <origin xyz="0 0 0" rpy="0 0 0" />
      <mass value="0.2" />
      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
    </inertial>
  </link>

  <joint name="left_arm_shoulder_lift_joint" type="revolute">
    <parent link="left_arm_shoulder_pan_link" />
    <child link="left_arm_shoulder_lift_link" />
    <origin xyz="0 0 0.035" rpy="0 0 0" />
    <axis xyz="0 1 0" />
    <limit lower="-1.57" upper="1.57" effort="30" velocity="2.0" />
  </joint>
  <link name="left_arm_shoulder_lift_link">
    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
    <inertial>
      <origin xyz="0.05 0 0" rpy="0 0 0" />
      <mass value="0.2" />
      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
    </inertial>
  </link>

  <joint name="left_arm_shoulder_roll_joint" type="revolute">
    <parent link="left_arm_shoulder_lift_link" />
    <child link="left_arm_shoulder_roll_link" />
    <origin xyz="0.09 0 0" rpy="0 0 0" />
    <axis xyz="1 0 0" />
    <limit lower="-1.57" upper="1.57" effort="30" velocity="2.0" />
  </joint>
  <link name="left_arm_shoulder_roll_link">
    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
    <inertial>
      <origin xyz="0 0 0" rpy="0 0 0" />
      <mass value="0.2" />
      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
    </inertial>
  </link>

  <joint name="left_arm_elbow_flex_joint" type="revolute">
    <parent link="left_arm_shoulder_roll_link" />
    <child link="left_arm_elbow_flex_link" />
    <origin xyz="0 0 0.05" rpy="0 0 0" />
    <axis xyz="0 1 0" />
    <limit lower="-2.09" upper="1.57" effort="30" velocity="2.0" />
  </joint>
  <link name="left_arm_elbow_flex_link">
    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
    <inertial>
      <origin xyz="0.05 0 0" rpy="0 0 0" />
      <mass value="0.2" />
      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
    </inertial>
  </link>

  <joint name="left_arm_forearm_rotation_joint" type="revolute">
    <parent link="left_arm_elbow_flex_link" />
    <child link="left_arm_forearm_rotation_link" />
    <origin xyz="0.1 0 0" rpy="0 0 0" />
    <axis xyz="1 0 0" />
    <limit lower="-3.14159" upper="3.14159" effort="30" velocity="2.0" />
  </joint>
  <link name="left_arm_forearm_rotation_link">
    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
    <inertial>
      <origin xyz="0 0 0" rpy="0 0 0" />
      <mass value="0.2" />
      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
    </inertial>
  </link>

  <joint name="left_arm_wrist_flex_joint" type="revolute">
    <parent link="left_arm_forearm_rotation_link" />
    <child link="left_arm_wrist_flex_link" />
    <origin xyz="0.03 0 0" rpy="0 0 0" />
    <axis xyz="0 1 0" />
    <limit lower="-1.57" upper="1.57" effort="30" velocity="2.0" />
  </joint>
  <link name="left_arm_wrist_flex_link">
    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
    <inertial>
      <origin xyz="0.02 0 0" rpy="0 0 0" />
      <mass value="0.2" />
      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
    </inertial>
  </link>

  <joint name="left_arm_wrist_yaw_joint" type="revolute">
    <parent link="left_arm_wrist_flex_link" />
    <child link="left_arm_wrist_yaw_link" />
    <origin xyz="0.04 0 0" rpy="0 0 0" />
    <axis xyz="1 0 0" />
    <limit lower="-3.14159" upper="3.14159" effort="30" velocity="2.0" />
  </joint>
  <link name="left_arm_wrist_yaw_link">
    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
    <inertial>
      <origin xyz="0 0 0" rpy="0 0 0" />
      <mass value="0.2" />
      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
    </inertial>
  </link>

  <joint name="left_arm_gripper_joint" type="prismatic">
    <parent link="left_arm_wrist_yaw_link" />
    <child link="left_arm_gripper_link" />
    <origin xyz="0.03 0 0" rpy="0 0 0" />
    <axis xyz="0 0 1" />
    <limit lower="0.0" upper="0.02" effort="20" velocity="0.5" />
  </joint>
  <link name="left_arm_gripper_link">
    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
    <inertial>
      <origin xyz="0 0 0" rpy="0 0 0" />
      <mass value="0.15" />
      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
    </inertial>
  </link>

  
  <joint name="right_arm_shoulder_pan_joint" type="revolute">
    <parent link="torso" />
    <child link="right_arm_shoulder_pan_link" />
    <origin xyz="-0.115 0 0.42" rpy="0 0 0" />
    <axis xyz="0 0 1" />
    <limit lower="-2.967" upper="2.967" effort="30" velocity="2.0" />
  </joint>
  <link name="right_arm_shoulder_pan_link">
    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
    <inertial>
      <origin xyz="0 0 0" rpy="0 0 0" />
      <mass value="0.2" />
      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
    </inertial>
  </link>

  <joint name="right_arm_shoulder_lift_joint" type="revolute">
    <parent link="right_arm_shoulder_pan_link" />
    <child link="right_arm_shoulder_lift_link" />
    <origin xyz="0 0 0.035" rpy="0 0 0" />
    <axis xyz="0 1 0" />
    <limit lower="-1.57" upper="1.57" effort="30" velocity="2.0" />
  </joint>
  <link name="right_arm_shoulder_lift_link">
    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
    <inertial>
      <origin xyz="0.05 0 0" rpy="0 0 0" />
      <mass value="0.2" />
      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
    </inertial>
  </link>
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

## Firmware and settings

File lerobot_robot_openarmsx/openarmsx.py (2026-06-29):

"""OpenArmsX — Bimanual 7-DOF mobile robot with lift and differential drive."""

from __future__ import annotations

import logging
import time
from functools import cached_property
from itertools import chain
from typing import Any

import numpy as np

from lerobot.cameras.utils import make_cameras_from_configs
from lerobot.motors import Motor, MotorCalibration, MotorNormMode
from lerobot.motors.feetech import FeetechMotorsBus, OperatingMode
from lerobot.robots.robot import Robot
from lerobot.robots.utils import ensure_safe_goal_position
from lerobot.utils.errors import DeviceAlreadyConnectedError, DeviceNotConnectedError

from .config_openarmsx import OpenArmsXConfig
from .lift_axis import OpenArmsXLiftAxis

logger = logging.getLogger(__name__)


# ---------------------------------------------------------------------------
# Helpers
# ---------------------------------------------------------------------------

def _make_arm_joint_names(prefix: str) -> list[str]:
    """Return joint names for a 7-DOF + gripper arm."""
    return [
        f"{prefix}_shoulder_pan",
        f"{prefix}_shoulder_lift",
        f"{prefix}_shoulder_roll",
        f"{prefix}_elbow_flex",
        f"{prefix}_forearm_rotation",
        f"{prefix}_wrist_flex",
        f"{prefix}_wrist_yaw",
        f"{prefix}_gripper",
    ]


LEFT_ARM_JOINTS = _make_arm_joint_names("left_arm")
RIGHT_ARM_JOINTS = _make_arm_joint_names("right_arm")
HEAD_JOINTS = ["head_pan", "head_tilt"]
WHEEL_JOINTS = ["base_left_wheel", "base_right_wheel"]


def _joint_names() -> list[str]:
    return LEFT_ARM_JOINTS + RIGHT_ARM_JOINTS + HEAD_JOINTS


def _state_keys() -> list[str]:
    return [f"{j}.pos" for j in _joint_names()] + ["x.vel", "theta.vel", "lift_axis.height_mm"]


def _motor_specs(use_degrees: bool) -> dict[str, tuple[int, str, MotorNormMode]]:
    """Return {name: (motor_id, model, norm_mode)} for every motor on the robot.

    The caller decides which bus each motor lands on — this is just the central
    registry so we never accidentally duplicate ID assignments.
    """
    arm_norm = MotorNormMode.DEGREES if use_degrees else MotorNormMode.RANGE_M100_100
    specs: dict[str, tuple[int, str, MotorNormMode]] = {}

    for i, name in enumerate(LEFT_ARM_JOINTS, start=1):
        mode = MotorNormMode.RANGE_0_100 if name.endswith("gripper") else arm_norm
        specs[name] = (i, "sts3215", mode)
    for i, name in enumerate(RIGHT_ARM_JOINTS, start=1):
        mode = MotorNormMode.RANGE_0_100 if name.endswith("gripper") else arm_norm
        specs[name] = (i, "sts3215", mode)
    specs["head_pan"] = (12, "sts3215", arm_norm)
    specs["head_tilt"] = (13, "sts3215", arm_norm)
    # Wheels — velocity mode, never calibrated in position space
    specs["base_left_wheel"] = (10, "sts3215", MotorNormMode.RANGE_M100_100)
    specs["base_right_wheel"] = (11, "sts3215", MotorNormMode.RANGE_M100_100)
    return specs


# ---------------------------------------------------------------------------
# Robot class
# ---------------------------------------------------------------------------

class OpenArmsX(Robot):
    """7-DOF dual-arm semi-humanoid robot with differential drive and lift.

    Motor bus topology
    ------------------
    **3-bus** (``port3`` is set — default):

    + ``port1`` — left arm (IDs 1-8) + head pan/tilt (IDs 12,13) … POSITION
    + ``port2`` — right arm (IDs 1-8) … POSITION
    + ``port3`` — lift (ID 9) + left wheel (ID 10) + right wheel (ID 11)

    **2-bus** (``port3 = None``):

    + ``port1`` — left arm + head
    + ``port2`` — right arm + lift + wheels  (mixed POSITION / VELOCITY)

    All arms are 7-DOF (3 shoulder + 1 elbow + 1 forearm + 2 wrist) + 1 gripper.
    """

    config_class = OpenArmsXConfig
    name = "openarmsx"

    def __init__(self, config: OpenArmsXConfig):
        super().__init__(config)
        self.config = config
        self._motor_specs = _motor_specs(config.use_degrees)

        # ── Calibration split ────────────────────────────────────────────
        # The calibration JSON stores *position* calibrations.  Wheels &
        # lift are velocity-controlled and use homing / full-range instead.
        cal = self.calibration

        def _maybe_cal(name: str) -> dict:
            return {k: v for k, v in cal.items() if k.startswith(name)} or None

        cal_left = _maybe_cal("left_arm") or _maybe_cal("head") or None
        cal_right = _maybe_cal("right_arm") or None
        cal_wheels = _maybe_cal("base") or None

        # ── Bus 1: left arm + head ──────────────────────────────────────
        self.bus1 = FeetechMotorsBus(
            port=self.config.port1,
            motors={
                n: Motor(*self._motor_specs[n])
                for n in LEFT_ARM_JOINTS + HEAD_JOINTS
            },
            calibration=cal_left or {},
        )

        # ── Bus 2: right arm + (optionally lift + wheels) ──────────────
        bus2_motors: dict[str, Motor] = {
            n: Motor(*self._motor_specs[n]) for n in RIGHT_ARM_JOINTS
        }

        if self.config.port3 is None:
            # 2-bus mode — wheels & lift share bus 2
            for n in WHEEL_JOINTS:
                bus2_motors[n] = Motor(*self._motor_specs[n])
            lift_bus = self.bus2  # will be assigned below
            wheel_cal = cal_wheels
        else:
            lift_bus = None  # placeholder; bus 3 not created yet
            wheel_cal = cal_wheels

        self.bus2 = FeetechMotorsBus(
            port=self.config.port2,
            motors=bus2_motors,
            calibration=cal_right or {},
        )

        # ── Bus 3 (3-bus mode only) ──────────────────────────────────────
        if self.config.port3 is not None:
            self.bus3 = FeetechMotorsBus(
                port=self.config.port3,
                motors={
                    n: Motor(*self._motor_specs[n]) for n in WHEEL_JOINTS
                },
                calibration=wheel_cal or {},
            )
            lift_bus = self.bus3
        else:
            self.bus3 = None
            # already set lift_bus = self.bus2 above

        # ── Lift Axis (always separate from the main feature dict) ──────
        self.lift_axis = OpenArmsXLiftAxis(self.config.lift, lift_bus)

        # ── Motor-group listings (for sync_read/write) ──────────────────
        self.left_arm_motors = LEFT_ARM_JOINTS[:]
        self.right_arm_motors = RIGHT_ARM_JOINTS[:]
        self.head_motors = HEAD_JOINTS[:]
        self.wheel_motors = WHEEL_JOINTS[:]
        self.arm_motors = self.left_arm_motors + self.right_arm_motors + self.head_motors

        # ── Cameras ──────────────────────────────────────────────────────
        self.cameras = make_cameras_from_configs(config.cameras)

    # ── Feature descriptors ───────────────────────────────────────────────

    @property
    def _state_ft(self) -> dict[str, type]:
        return dict.fromkeys(_state_keys(), float)
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

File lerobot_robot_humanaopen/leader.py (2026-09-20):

"""HumanaOpen leader-arm teleoperator.

Leader arm: open-arms-mini structure, 7-DOF + gripper, STS3215 C046 (7.4V),
8 servos per arm (IDs 1-8).

Design notes:
- Joint naming matches the follower arm exactly; the dual-arm class outputs
  left_arm_*/right_arm_* prefixes, so during teleoperation
  leader.get_action() can feed directly into follower.send_action() with zero conversion.
- Calibration: natural hang + gripper closed is the zero point (consistent with
  the follower's mid-position convention).
- Direction flips / wrist remapping reference the official lerobot openarm_mini
  (same-source hardware, verified).

Usage (dual-arm):
    from lerobot_robot_humanaopen.leader import BiHumanaOpenLeader, BiHumanaOpenLeaderConfig
    cfg = BiHumanaOpenLeaderConfig(
        id="leader",
        left_arm_port="/dev/ttyACM2",
        right_arm_port="/dev/ttyACM3",
    )
    leader = BiHumanaOpenLeader(cfg)
    leader.connect(calibrate=True)

Calibration files:
    ~/.cache/huggingface/lerobot/calibration/teleoperators/humanaopen_leader/{id}_left.json
    ~/.cache/huggingface/lerobot/calibration/teleoperators/humanaopen_leader/{id}_right.json
"""

from __future__ import annotations

import logging
from dataclasses import dataclass
from functools import cached_property
from typing import Any

from lerobot.motors import Motor, MotorCalibration, MotorNormMode
from lerobot.motors.feetech import FeetechMotorsBus, OperatingMode
from lerobot.teleoperators.config import TeleoperatorConfig
from lerobot.teleoperators.teleoperator import Teleoperator

logger = logging.getLogger(__name__)

# Global registry of connected robots: registered by HumanaOpen.connect() so
# HumanaOpenTeleop can read the head/lift initial positions (during record the
# teleop has no direct reference to the robot).
_CONNECTED_ROBOTS: list[Any] = []

# Globally shared pynput keyboard listener: avoids multiple Listeners competing
# for the keyboard on Linux/X11, which would scramble key events (record's
# init_keyboard_listener also starts its own Listener).
_KB_LISTENER = None
_KB_CALLBACKS: list[Any] = []


def _kb_on_press(key) -> None:
    try:
        ch = key.char
    except AttributeError:
        return
    if ch:
        for cb in _KB_CALLBACKS:
            try:
                cb(ch, True)
            except Exception:
                pass


def _kb_on_release(key) -> None:
    try:
        ch = key.char
    except AttributeError:
        return
    if ch:
        for cb in _KB_CALLBACKS:
            try:
                cb(ch, False)
            except Exception:
                pass


def register_keyboard_callback(callback) -> None:
    """Register a callback(ch, is_pressed) for global shared keyboard events."""
    global _KB_LISTENER
    _KB_CALLBACKS.append(callback)
    if _KB_LISTENER is None or not _KB_LISTENER.is_alive():
        from pynput import keyboard as kb

        _KB_LISTENER = kb.Listener(on_press=_kb_on_press, on_release=_kb_on_release)
        _KB_LISTENER.start()


def get_connected_robot() -> Any | None:
    """Return the most recently connected HumanaOpen robot, or None."""
    return _CONNECTED_ROBOTS[-1] if _CONNECTED_ROBOTS else None


def register_robot(robot: Any) -> None:
    """Register a connected robot (called from HumanaOpen.connect)."""
    _CONNECTED_ROBOTS.append(robot)

# Joint naming matches the follower (see humanaopen.py _make_arm_joint_names)
JOINT_NAMES = [
    "shoulder_pan",
    "shoulder_lift",
    "shoulder_roll",
    "elbow_flex",
    "forearm_rotation",
    "wrist_flex",
    "wrist_yaw",
    "gripper",
]

# Per-side direction flips (inverted on read), referencing the official
# openarm_mini SIDE_MOTORS_TO_FLIP.
# Note: this is the direction signature for this specific "official leader x
# official follower" hardware pairing. If your leader/follower assembly or
# servo mounting differs from the official one, adjust per joint based on tests
# (see examples/diagnose_teleop.py).
DEFAULT_SIDE_MOTORS_TO_FLIP: dict[str, list[str]] = {
    "left": ["shoulder_pan", "shoulder_roll", "elbow_flex", "forearm_rotation", "wrist_flex", "wrist_yaw"],
    "right": ["shoulder_pan", "shoulder_lift", "shoulder_roll", "elbow_flex", "forearm_rotation", "wrist_yaw"],
}

# Wrist flex<->yaw remapping (symmetric, its own inverse), referencing the
# official JOINT_REMAP.
# Official note: "deliberately swapped... feels more natural given how the human wrist moves".
# If your follower's wrist structure does not need the swap, empty the dict (adjust per testing).
DEFAULT_JOINT_REMAP = {"wrist_flex": "wrist_yaw", "wrist_yaw": "wrist_flex"}


@TeleoperatorConfig.register_subclass("humanaopen_leader")
@dataclass
class HumanaOpenLeaderConfig(TeleoperatorConfig):
    """Single-arm leader configuration.

    calibration_mode:
        - "full" (default): zero + record real ranges per joint. The
          action/observation normalization space is strictly consistent with
          the follower, teleoperation and data recording share the same
          calibration, no re-calibration needed.
        - "quick": zero + full joint range [0, 4095] (official openarm_mini
          simplified approach). Suitable for pure realtime teleoperation;
          re-calibrate to "full" before recording data for training.

    flip_joints:
        List of joints that need direction flips per side. Defaults to the
        official table; adjust per testing (diagnose_teleop.py).
    joint_remap:
        Joint remapping dict (source joint -> target joint). Defaults to the
        wrist flex<->yaw swap; empty it if not needed.
    """
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

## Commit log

2026-06-29 Fix: J7 wrist_roll → wrist_yaw (human-like kinematics)
    [openarmsx.py]
2026-08-17 feat: complete teleop-data-train-infer pipeline for HumanaLite
    - Full-body 21-DOF teleoperation (leader arms + keyboard head/lift/base)
    - Data collection via record_data.py (Python API, bypasses lerobot CLI enum)
    - ACT training with lerobot-train
    - Inference with eval_data.py (policy + human override toggle)
    - Lift speed boost (BIT2=0): 1.94 → 8.72 mm/s
    - Lift zero persistence (免归零 across sessions)
    - Head tilt EPROM unlock: 58° → 78.7° mechanical range
    - Cameras: 3+1 USB MJPG 30/25fps
    - wheel_dir_signs fix for correct i/j/k/l mapping
    - README with full pipeline documentation
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2026-08-22 fix: calibrate=False silently restores calibration without prompting
    [humanaopen.py]
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2026-08-22 fix: struct.pack format <II → <III (magic + n_floats + n_images = 3 values)
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2026-08-23 refactor: revert to pynput toggle mode for override (press e to switch)
2026-08-23 fix: reset ACT action queue on override OFF (re-plan from current pose, not stale queue)
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2026-08-27 fix: ZMQ mode head calibration fallback (calibration is empty on Host side)
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2026-08-28 fix: lift uses vel control (not height_mm) — prevents runaway descent in dual-machine
2026-08-28 docs: add wheel_dir_signs to Host startup commands (fix ikjl direction in dual-machine)
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2026-08-28 fix: wheel_dir_signs {left:-1, right:-1} — both wheels inverted (x=+10 now drives forward)
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2026-08-28 fix: retry on servo read + skip-fault tolerance in host loop (prevent crash)
    [humanaopen.py]
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2026-08-29 fix: proper dual-machine record/eval via registered ZMQ Robot + translate all comments to English
    - HumanaOpenClient is now a full lerobot Robot (name/cameras/features/
    lift_axis), exported in __init__ so lerobot's make_robot_from_config
    constructs it directly — record_data.py no longer monkey-patches
    (patch was inert: record() binds the name at import time, raising
    'Could not locate device class HumanaOpenClient').
    - record_data.py: delete broken ClientRobot wrapper (missing .name/
    .cameras, images-as-float and dropped x.vel/theta.vel schema);
    pass camera schema into HumanaOpenClientConfig so datasets record
    21-DOF action incl. base velocities + camera videos.
    - eval_data.py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
2026-08-29 feat(i18n): translate all remaining runtime strings (print/argparse) to English
    All scripts now contain zero CJK characters anywhere (comments, docstrings,
    print output, argparse help). Operator-facing messages for teleop, base
    tests, wheel/head-tilt/lift diagnostics, gripper tests and servo speed
    diagnostics are now English. Includes check_phase.py which was missed by the
    initial sweep.
2026-08-29 docs: Host startup examples now include cameras (default_cameras) + fix duplicated .run()/orphan lines in zh/fr/ko
    Dual-machine Host examples previously showed cameras={}, so users following
    the guide started the Host without cameras and saw no image feed on the
    client (teleop 'Host cameras received: none'). Now every Host block uses
    config_humanaopen.default_cameras() with a note that cameras={} is only for
    pure teleop without image views. Also fixed ').run().run()' copy-paste bugs
    and orphan 'HumanaOpenHost(HumanaOpenConfig()).run()' lines in zh/fr/ko.
2026-08-29 docs: expand Host camera example — explicit OpenCVCameraConfig for each camera (replace default_cameras())
    Users asked how to specify camera device numbers (index_or_path). Every Host
    startup block now shows the full cameras dict with explicit
    OpenCVCameraConfig(index_or_path='/dev/videoN', fps=30, 640x480, fourcc='MJPG')
    for head/left_wrist/right_wrist, plus an inline note to run
    lerobot-find-cameras on the board and adjust /dev/videoN. Command verified:
    HumanaOpenHost construct OK, cameras resolved to the 3 paths. All 4 languages.
2026-08-29 fix(host): camera thread per-camera try + keep last frame + log failures; client slow-joiner wait
2026-08-29 feat(zmq): JPEG-compress image frames over ZMQ (default q85, ~13% of raw size)
    - Host _serialize_obs: encode each RGB frame with cv2.imencode (BGR 转换),
    add 1-byte fmt (1=jpeg, 0=raw) + payload_len to the wire protocol
    - Client _deserialize_obs: decode fmt=1 via imdecode + BGR2RGB, fmt=0 raw
    - HumanaOpenHostConfig.jpeg_quality: 0 = raw frames (huge), 85 default
    (~30-80KB/frame vs 921KB raw) — fixes bandwidth saturation on 100Mbps
    - cv2 optional on host: missing opencv falls back to raw frames
    - Verified round-trip: RGB color preserved, q85 → ~13% of raw size,
    quality param scales file size monotonically
2026-08-29 perf(zmq): fix teleop latency — CONFLATE client obs + image rate divider on host
    Severe latency in dual-machine teleop with images. Root causes:
    1. Client SUB queued every obs (with ~100KB JPEG image payloads); reading a
    stale backlog meant constantly lagging. CONFLATE=1 keeps only the newest
    observation → we always act on fresh state (humanaopen_client.py).
    2. Host sent images on EVERY 30Hz control frame: 3 cameras ≈ 100-300KB/frame
    saturated the link and the synchronous send_multipart blocked the action
    channel. Now images attach only every image_fps_divider frames (default 3
    → ~10Hz image stream) while control stays 30Hz (humanaopen_host.py).
    3. Camera thread captur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
2026-08-29 fix(client): replace ZMQ_CONFLATE with non-blocking drain — CONFLATE crashes on multipart
    libzmq asserts '!_more (src/fq.cpp:80)' when ZMQ_CONFLATE=1 is set on a SUB
    socket that receives multi-part messages (issue zeromq/libzmq#3373). Our obs
    frames are 2-part multipart ([b'obs', payload]), so the client aborted with
    core dump right after 'Connecting follower...'.
    get_observation() now polls the socket in non-blocking mode and drains all
    pending multipart frames, keeping only the freshest one — same 'latest wins'
    semantics as CONFLATE but multipart-safe. Verified: 3 queued frames drain to
    the newest (head_pan.pos==2.0) with no crash.
2026-08-29 fix(client): persist image cache across calls — divider>1 dropped images
    Host sends images only every image_fps_divider frames (default 3 -> 10Hz
    images vs 30Hz joint state). The drain-based get_observation() replaced each
    obs wholesale, so a fresh non-image frame erased the last picture — after
    adding the divider, rerun showed no camera feed even though the host was
    streaming.
    Now: images received in any drain are stored in _img_cache (thread-safe) and
    re-attached to the freshest joint frame before returning. State stays 30Hz
    fresh, images persist at their own ~10Hz rate. Verified end-to-end with a
    mixed no-image/image frame stream: latest state + latest image both correct
    across multi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
2026-08-30 perf(teleop): raise rerun display rate 5Hz -> 15Hz (LeKiwi benchmark)
    Reference: lerobot_alohamini lekiwi teleoperate.py logs rerun EVERY frame
    (30Hz) with no throttle. Our 200ms gate (5Hz) made the camera view look
    stalled. Throttle now at 1/15s = 15Hz: 3x smoother visualization while
    keeping headroom for the 30FPS control loop.
2026-08-30 refactor(zmq): migrate transport to AlohaMini architecture — PUSH/PULL + multipart JPEG, 5 cameras OK
    Adopted from lerobot_alohamini (informed by lekiwi+xlerobot convergence):
    - obs: PUB→PUSH + SNDHWM=1, send NOBLOCK + drop-if-busy → host loop never
    blocks, wire always carries newest frame (replaces PUB slow-joiner drops)
    - message: custom binary → multipart [json(state), cam_key, jpeg_bytes, ...];
    JPEG binary (not base64), q70 default (AlohaMini's 5-camera tuned value)
    - cmd: multipart binary → JSON single-frame over PULL/CONFLATE (host) and
    PUSH (client)
    - client: SUB→PULL + RCVHWM=1 + drain-to-newest; Poller handshake with
    connect_timeout_s → fails fast (5s) instead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
2026-08-30 perf(config): jpeg_quality default 70 -> 85 (3 cameras have ample bandwidth)
    q70 was AlohaMini's tuning for 5 cameras. We run 3 cameras: real-scene JPEG
    frames are ~20-25KB at q85, so even 30Hz x 3 = 0.7MB/s at full image rate —
    well under 100Mbps. Raising to q85 improves recorded/training image quality
    with zero bandwidth risk. (Worst-case noise frames at q85 x30Hz x3 = 20MB/s
    still fine at divider=3 teleop; collection typically uses divider=1 but real
    scenes stay ~1MB/s.)
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2026-08-30 fix(teleop): pass cameras schema to ZMQ client — images were filtered out
    After the AlohaMini multipart migration, _parse_observation_multipart skips
    frames whose camera name is not in client._cameras_ft (derived from
    config.cameras). teleop built HumanaOpenClientConfig WITHOUT cameras, so
    camera_names was empty → every JPEG frame was dropped: joints worked (JSON
    head parses independently) but rerun showed nothing.
    Fix: pass cams as the schema (names + shapes). record_data.py and eval_data.py
    already pass cameras=—teleop was the only script missing it. --no-cameras
    still works as intended (empty schema → client accepts no image frames).
    Verified: without schema images filtered (rep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
2026-08-30 perf(teleop): compress rerun images (921KB->25KB) — viewer no longer lags
    log_rerun_data default compress_images=False sends FULL RGB (640x480x3 =
    921KB) per image to the viewer process. 3 cams at 15Hz = ~41MB/s into the
    viewer, which falls behind => display-only delay (control is unaffected; it
    runs on the separate ZMQ cmd channel).
    compress_images=True encodes to JPEG (~25KB) in the SDK before gRPC: viewer
    load drops ~37x. Display-only change; recorded dataset is untouched (it comes
    from ZMQ obs, not rerun).
2026-08-30 fix(teleop): auto-discover rerun viewer — PATH lacked 'rerun', spawn failed silently
    Symptom: rerun showed camera entities but no rendered frames + 'Sender has
    been blocked for over 5 seconds' warnings. Root cause: rr.spawn() needs a
    'rerun' executable in PATH; the client shell's PATH omitted the conda env bin
    (conda activate not fully applied). lerobot's init_rerun wraps spawn in no
    error path, so the failure was silent: SDK started a viewer-less gRPC server
    on 9876, no GUI ever connected, and the log channel filled up (blocked).
    Fix: before init_rerun, if shutil.which('rerun') misses, prepend the conda env
    bin (sys.executable dir) or the bundled rerun_sdk/rerun_cli dir to PATH.
    Verified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
2026-08-31 fix(leader,record): lazy-load head/lift state so record holds position, foxglove auto-open
    Behaviors during data collection now match the standalone teleop:
    1+3. HumanaOpenTeleop.connect() runs BEFORE robot.connect() in lerobot's
    record() flow, so get_connected_robot() returned None and head/lift
    stayed at their 0.0 defaults -> head snapped to center and the lift
    P-controller drove toward 0mm at record start. Now the state is
    lazy-loaded on the FIRST get_action() (after the robot is up), reading
    the current head_pan/head_tilt and lift height so they are held at
    their real positions (issue #1 lift no longer descends to 0, #3 head
    no longer recenters).
    2. Lift kee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
    [leader.py]
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2026-09-09 fix(host): enable INFO logging + lift homing diagnostics
    - humanaopen_host.run(): add logging.basicConfig(INFO) so lift homing
    messages are visible on console (previously swallowed by WARNING default)
    - restore_zero(): log each decision path (no file / unreadable / mismatch /
    match) so it's clear whether re-home is triggered and why
    - home(): log drive-down entry with target velocity
    [lift_axis.py]
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2026-09-09 feat(host): add force_lift_home option to re-home after mechanical re-assembly
    restore_zero() only compares raw encoder ticks (tol=30) against the zero
    file; after re-assembly the carriage position no longer matches the saved
    state even though ticks happen to match, so the lift silently restores a
    wrong height and u/h become unpredictable. force_lift_home=True skips the
    zero file entirely and re-runs stall-detection homing, rewriting the file.
    [humanaopen.py]
2026-09-09 fix(lift): enable torque before homing — home() ran with torque disabled
    bus.connect() is handshake-only and never enables torque; lift_axis.configure()
    only sets VELOCITY mode. In connect() the lift homes BEFORE parent.configure()
    enables torque, so home() wrote Goal_Velocity to a torque-disabled motor:
    position never changed -> instant 'stalled' -> false homing that saved a
    garbage zero at the physical top. enable torque+unlock at home() entry so
    stall-detection actually drives the carriage to the bottom.
    [lift_axis.py]
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2026-09-09 fix(lift): set Acceleration=254 on configure — SRAM resets to 0 per power cycle
    Acceleration (SRAM addr 41) is 0 after every power-on, giving a very slow
    velocity ramp: Goal_Velocity=110 only reached ~1.7mm/s instead of the
    commanded ~10.7mm/s (measured). lerobot's configure_motors() sets 254
    (fastest ramp) for all its robots, but the HumanaOpen host never called it,
    so the lift silently capped every speed command. Write it explicitly in
    lift_axis.configure().
    [lift_axis.py]
2026-09-09 feat(lift): auto-switch Phase BIT2=0 on connect — no manual switch needed
    Phase BIT2 selects Goal_Velocity unit (0=50 step/s/raw, 1=1 step/s/raw).
    All lift speed constants assume BIT2=0, but firmware default / re-flash
    resets it to BIT2=1 which silently caps every speed command by 50x.
    configure() now reads Phase and switches to BIT2=0 (EPROM write, survives
    reboot) so teleop / record / eval all get correct speed automatically
    without running examples/switch_phase_bit2.py manually.
    [lift_axis.py]
2026-09-09 feat(lift): auto-invalidate stale zero file after motor replacement
    restore_zero() now checks two things beyond the raw tick match:
    1. Model_Number identity — a replacement motor with a different model
    invalidates the saved zero state (re-home).
    2. Height plausibility — even a same-model replacement can leave the old
    extended_ticks pointing at a physically impossible height; re-home when
    the restored height falls outside soft range + margin. State is rolled
    back on failure so the re-home starts clean.
    New zero files record model_number; older files skip the identity check.
    [lift_axis.py]
2026-09-09 feat(lift): add triangle-consistency check — catches same-model motor swaps
    extended_ticks is the multi-turn displacement since home, so it must agree
    with (current_tick - abs_tick_at_home) modulo one revolution. A replacement
    motor has a different encoder origin: even when the raw tick coincidentally
    matches the saved last_tick (within tol), this relation breaks. Verified with
    real data: normal restart diff=1 (restore), replaced-motor coincidental match
    diff=931 (re-home).
    [lift_axis.py]
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2026-09-09 fix(host): throttle no-client log spam — watchdog + dropped obs
    Without a client the host logged two lines per frame (~30/s each):
    - 'Dropping observation' from zmq.Again on every obs send
    - 'Base & lift motors stopped' from the watchdog stop_base() on every frame
    Now: dropped-obs logs at most once per 5s; watchdog logs once per episode
    (edge-triggered, resets when a command arrives). The safety action itself
    still runs every frame — only the logging is throttled. stop_base() gains
    log=False for the watchdog caller; disconnect() keeps logging.
    [humanaopen.py]
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2026-09-10 fix(leader): use RANGE_M100_100 to match follower — restore 1:1 teleop
    Leader arm joints were hardcoded to MotorNormMode.DEGREES (output ±180°)
    while HumanaOpenConfig defaults use_degrees=False → follower expects
    RANGE_M100_100 (input -100..+100). teleop feeds leader.get_action()
    straight into follower.send_action(), so a DEGREES leader overdrives the
    follower: leader at 75% travel (+90°) maps to follower 95%, and beyond
    +100° the recipient clamps — follower maxes out while leader is only
    ~55% through its range.
    Fix: honor the existing (unused) use_degrees flag in the Motor setup,
    default it to False matching the follower, and thread it through the
    dual-arm config. Same calibrated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
    [leader.py]
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2026-09-11 perf(latency): reduce teleop lag — no retries, parallel arm reads, IMMEDIATE, latency display
    Latency analysis (2 deep dives: code trace + ZMQ research) showed the
    transport (~40-100µs/hop) is NOT the bottleneck; the visible lag comes from:
    1. Host sync_read with num_retry=3: a flaky bus stalls the 30Hz loop up to
    ~140ms (4 frames) per failed read. Removed retries — one bad sample is
    cheaper than a 4-frame freeze, and the next frame re-reads anyway.
    Also merged the left-arm + head reads on bus1 into ONE sync_read (was 2
    round trips).
    2. Leader get_action() read left then right arm serially (2 independent
    buses, each its own bus/thread-safe) — now concurrent, waits for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
    [humanaopen.py, leader.py]
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2026-09-11 fix(teleop): revert IMMEDIATE (blocks control loop), add SNDTIMEO+send fault-tolerance
    Diagnostic data: client loop is clean (leader 1.6ms, total 1.7ms) but net
    latency swung 56ms -> 19s and the host watchdog fired repeatedly + crashed
    on a lift write. Root causes:
    1. IMMEDIATE=1 on the client PUSH: under connection jitter a blocking send
    can stall the whole teleop loop (no SNDTIMEO). Reverted; host-side drain
    already handles stale-command skipping, so IMMEDIATE only added risk.
    2. Blocking send with no timeout: replaced by CONFLATE + SNDTIMEO=10ms,
    dropping a frame is fine (host applies newest only).
    3. Host crashed when the lift motor's bus write failed mid-session — arm
    com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
    [humanaopen.py]
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2026-09-12 perf(right-arm): dedup unchanged wheel/lift writes — bus2 now near-idle when idle
    The last bottleneck: even with reads downsampled, send_action still wrote
    x.vel/theta.vel=0 and lift_axis.vel=0 to bus2 EVERY frame (teleop sends the
    full action dict each cycle). Two extra serial round-trips/frame on the
    right-arm bus even when nothing moved.
    - wheel: skip Goal_Velocity sync_write if raw values unchanged
    - lift: skip Goal_Velocity write if vel unchanged (first 0 is still written,
    so the motor always receives its stop)
    With zero-speed teleop (the common case) bus2 now carries only the right
    arm's read + write per frame — same as bus1 for the left arm. 3-bus mode
    unaffected (wheels/lift a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
    [humanaopen.py, lift_axis.py]
2026-09-12 feat(teleop): EMA-smooth leader positions — kill hand tremor for smooth follower tracking
    Human hands have 8-12Hz tremor that the leader encoder picks up; the
    follower chases every micro-jitter, which reads as stickiness/non-smooth
    tracking on high-inertia joints (shoulder_lift against gravity). Add
    per-joint EMA smoothing (alpha=0.35) in HumanaOpenLeader.get_action(),
    configurable via smoothing= on leader configs and threaded through the
    dual-arm config. ~1 frame of lag at 60Hz, kills tremor while keeping brisk
    moves.
    [leader.py]
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2026-09-12 perf(arm): set Acceleration=254 on all follower arm joints — same fix as lift
    All arm servos also ship with Acceleration=0 (SRAM resets on power-up),
    giving a very slow velocity ramp: when chasing a fast leader move the joint
    creeps toward the target and teleop feels laggy/jumpy, most noticeable on
    high-inertia shoulder_lift against gravity (right arm slightly worse).
    Write 254 (fastest ramp) in _config_arm, matching the lift fix. P/I/D
    unchanged.
    [humanaopen.py]
2026-09-12 feat(config): arm_p_gain configurable — test P=48 via config instead of script
    Running set_p while the host holds the serial port caused handshake errors
    (missing motor 13 / incorrect status). Configuring P through HumanaOpenConfig
    avoids the host-vs-script port race: host writes P_Coefficient=arm_p_gain at
    configure(), so the benchmark is reproducible and no manual script needed.
    Default 16 preserved; raise to 48 to test tighter tracking.
    [humanaopen.py]
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2026-09-19 feat(urdf): complete humanaopen.urdf skeleton with full kinematic tree + meshes
    - 24 links / 23 joints: base (differential wheels), lift (prismatic),
    torso, head pan/tilt, left+right arms (7-DOF + gripper each)
    - joint names mirror lerobot_robot_humanaopen/humanaopen.py exactly
    - 26 STL meshes copied into urdf/meshes/ (HumanaOpen_stl + Open-arms-mini J1-J8)
    - every link has visual mesh (mm->m scale 0.001), collision box, estimated inertial
    - arm joint mapping from open-arms-mini README (J1=pan, J2=lift, J3=roll,
    J4=elbow, J5=forearm, J6=wrist flex, J7=wrist yaw, J8=gripper L/R)
    - origins/inertia are estimates; mesh filenames authoritative
    [1.GripperFin-V3.stl, 10.Torso-V23.stl, 11.HeadHousing_V13.stl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]
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2026-09-19 fix(urdf): correct mesh origins & mirror right arm
    - body STL meshes recentred: HumanaOpen CAD exports had geometry at
    (165,160)mm in each file's XY quadrant; visual origins now compensate
    so chassis/lift/torso/head sit centred on their link frames
    - wheels lowered to ground (z=0.032) instead of embedded in chassis
    - right arm joint X offsets mirrored (shoulder_roll/forearm/wrist/gripper)
    so it no longer crosses the torso midline
    - gripper fins mounted on inboard side of each J8 jaw (L/R symmetric)
    - verified with check_urdf + per-mesh world-center audit (arms now
    mirror-symmetric, chassis centred, wheels on ground)
    [humanaopen.urdf]
2026-09-19 fix(urdf): physical grounding - wheels support chassis
    Dynamic test (PyBullet) exposed: base_link collision box (0.20x0.20x0.10
    centred at z=0) sat directly on the ground and lifted the wheels off it,
    so the robot could not drive.
    - base_link collision shrunk to 0.18x0.18x0.06 at z=0.03, clearing the
    wheel wells
    - wheel collision cylinders oriented along roll axis (Y) via rpy
    - verified in sim: chassis has zero ground contact, both wheels carry the
    load (3/2 contacts), robot drives +0.26m in 2.5s, lift + arms work,
    stays stable through motions
    [humanaopen.urdf]
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2026-09-20 fix(teleop): suppress leader/follower arm jitter with adaptive EMA + deadband writes
    Leader side (lerobot_robot_humanaopen/leader.py):
    - Speed-adaptive EMA alpha: rest alpha_min=0.15 for strong tremor
    filtering, motion alpha_max=smoothing so brisk moves are not dragged
    - Output deadband (default 0.1): hold last emitted value until the
    smoothed signal actually moves, freezing a stationary arm instead of
    re-targeting the follower with encoder self-noise (~1-2 ticks)
    - Gripper gets the deadband too (no EMA, hand-driven open/close)
    Follower side (humanaopen.py send_action):
    - Goal_Position write deadband (config.goal_deadband=0.1): skip targets
    whose change from the last written value i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
    [humanaopen.py, leader.py, test_leader_jitter.py]
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2026-09-21 fix(obs): unwrap continuous-rotation joints so multi-turn reads stay monotonic
    Present_Position wraps at ±2048 raw (half of the 4096 step/rev scale). A joint
    rotating past half a turn snaps to the other side; without unwrapping,
    lerobot's DEGREES/RANGE norm folds a multi-turn joint into a violent flip.
    Track each joint's previous raw and add/subtract a full revolution (4096)
    whenever the step-delta exceeds half a turn. Skipped for gripper (single-stroke
    joint, never crosses the wrap) and wheels (velocity path, never position).
    [humanaopen.py]
